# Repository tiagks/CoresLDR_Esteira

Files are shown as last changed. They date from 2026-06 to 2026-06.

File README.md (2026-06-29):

# Sensor de cores feito com um resistor LDR

## Objetivo

Desenvolver um sistema embarcado baseado no microcontrolador RP2040 capaz de identificar a cor de brinquedos em uma esteira de produção por meio de um sensor LDR, acionando um servomotor acoplado a um braço deflector para direcionar ou descartar automaticamente cada peça conforme sua cor, garantindo o controle de qualidade na linha de produção.

## Descrição Geral do Sistema

O sistema utiliza três LEDs (vermelho, verde e azul) que iluminam o objeto sobre a esteira sequencialmente. Para cada cor de LED acesa, um LDR mede a tensão refletida pelo objeto via ADC do RP2040 — formando uma assinatura RGB em voltagem para cada peça.

Antes de entrar em operação, o sistema passa por duas etapas de calibração via interface serial (UART/USB): primeiro, a calibração do tempo de decaimento do LDR (para garantir que o canal anterior apagou completamente antes de acender o próximo); depois, o treinamento de até 7 perfis de cor, incluindo obrigatoriamente o perfil NONE — a assinatura da esteira vazia, usada como filtro de ruído.

Durante a operação contínua, a cada leitura o firmware calcula a distância euclidiana no espaço RGB entre a leitura atual e todos os perfis treinados. Um filtro de limiar rejeita reflexos fracos da própria esteira. Se uma peça válida for identificada, o servomotor é travado no ângulo configurado para aquela cor por 2,8 segundos — tempo suficiente para a peça passar pelo braço deflector e ser direcionada ou descartada. Um LED RGB de status pisca em branco enquanto o sistema aguarda peças.

Toda a configuração e monitoramento é feita via comunicação serial (UART/USB), sem display físico.

## Diagrama de Blocos

```mermaid
flowchart LR
    C1[Inicializa o sistema] --> C2[Mede latência\ndos LEDs]
    C2 --> C3{Calibrar cor\nou iniciar sensor?}
    C3 -- Calibrar --> C4[Usuário\nescolhe a cor]
    C4 --> C5[Coloca objeto\nno sensor]
    C5 --> C6[LEDs piscam\nsequencialmente]
    C6 --> C7[LDR registra\nresistência por canal]
    C7 --> C8[Divisor de tensão\nconverte em tensão]
    C8 --> C9[ADC do RP2040\nlê os valores]
    C9 --> C10[RP2040 armazena\nassinatura RGB]
    C10 --> C11[Usuário define\nângulo do servo]
    C11 --> C3
    C3 -- Iniciar sensor --> OP1[LEDs piscam\nsequencialmente]
    OP1 --> OP2[LDR registra\nresistência R, G, B]
    OP2 --> OP3[Divisor de tensão\nconverte em tensão]
    OP3 --> OP4[ADC do RP2040\nlê os valores]
    OP4 --> OP5[Firmware compara com\ncalibrações armazenadas]
    OP5 -- Cor reconhecida --> OP6[Servo aciona no\nângulo calibrado]
    OP5 -- Esteira vazia\nou ruído --> OP7[Aguarda\nLED pisca branco]
    OP6 --> OP8{Cor correta?}
    OP8 -- Sim --> OP9[Braço para a direita\nPeça segue produção]
    OP8 -- Não --> OP10[Braço para a esquerda\nPeça descartada]
```

## Hardware

### Esquema Elétrico do sensor de cor LDR
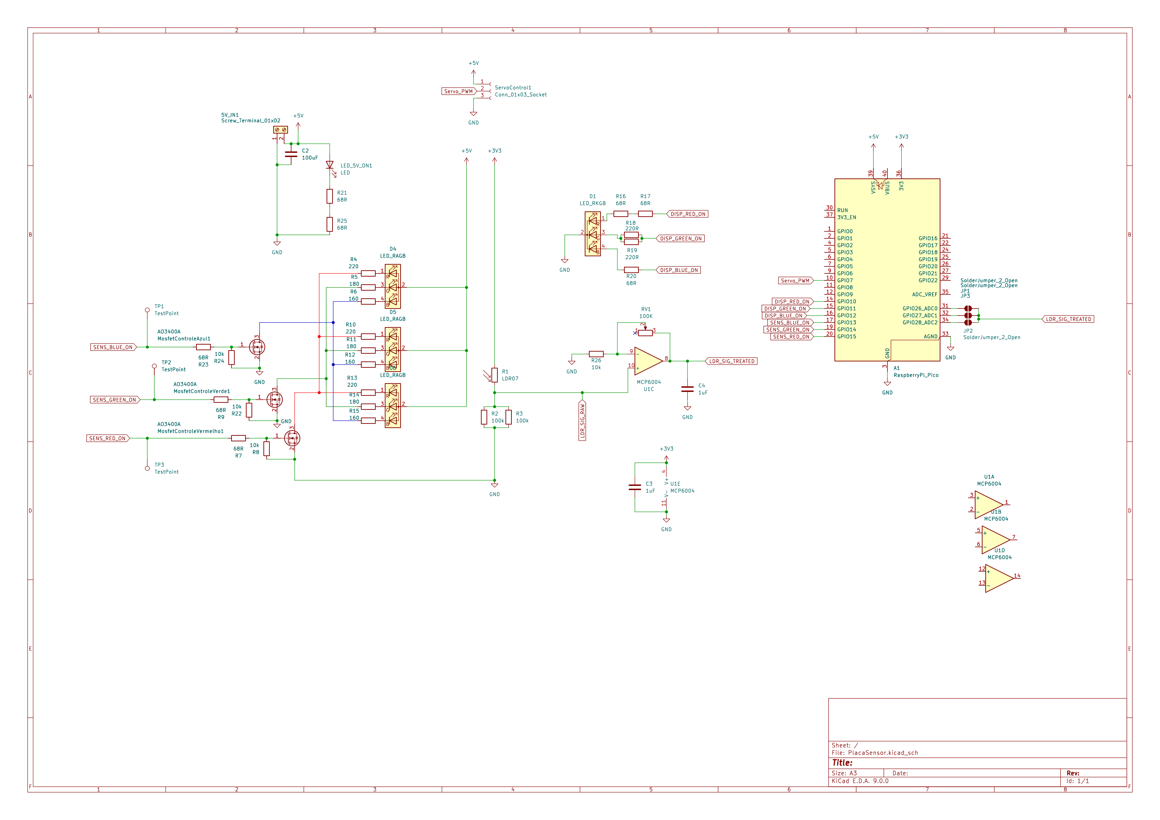
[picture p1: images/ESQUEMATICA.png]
Esquemático


### PCB do Sensor

#### Top Layer

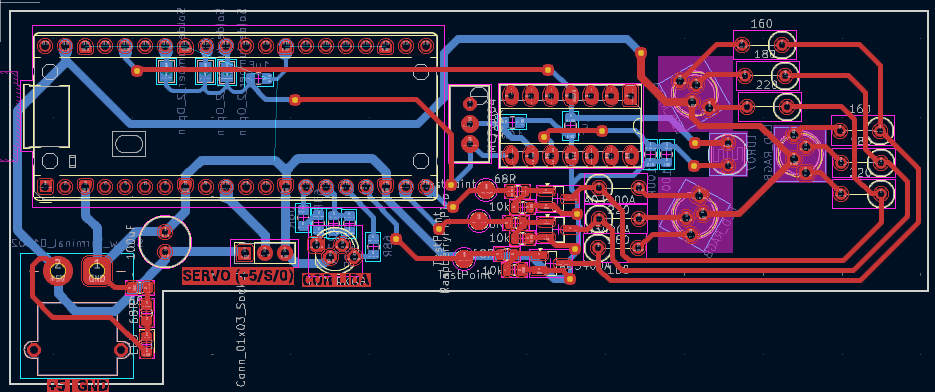
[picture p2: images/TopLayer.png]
PCB Top Layer do controlador


#### Bottom Layer

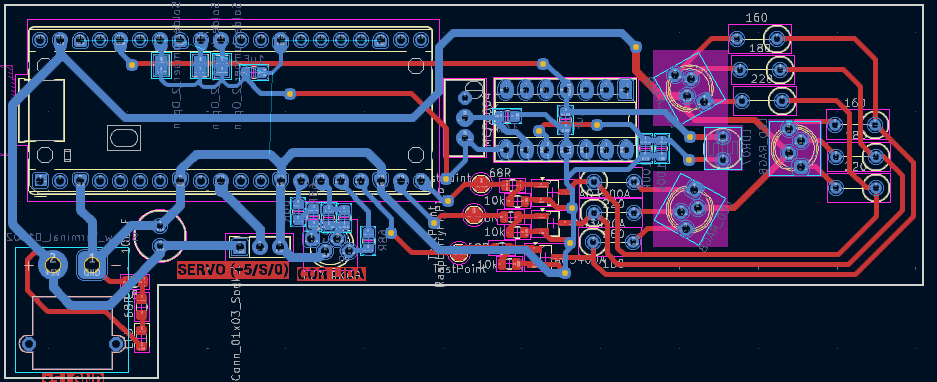
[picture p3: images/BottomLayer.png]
PCB Bottom Layer do controlador


## Funcionalidades

- Leitura analógica de cor via sensor LDR
- Condicionamento de sinal (amplificação/filtragem)
- Classificação da cor identificada via firmware no RP2040
- Acionamento automático do motor da esteira/atuador

## Projeto Finalizado
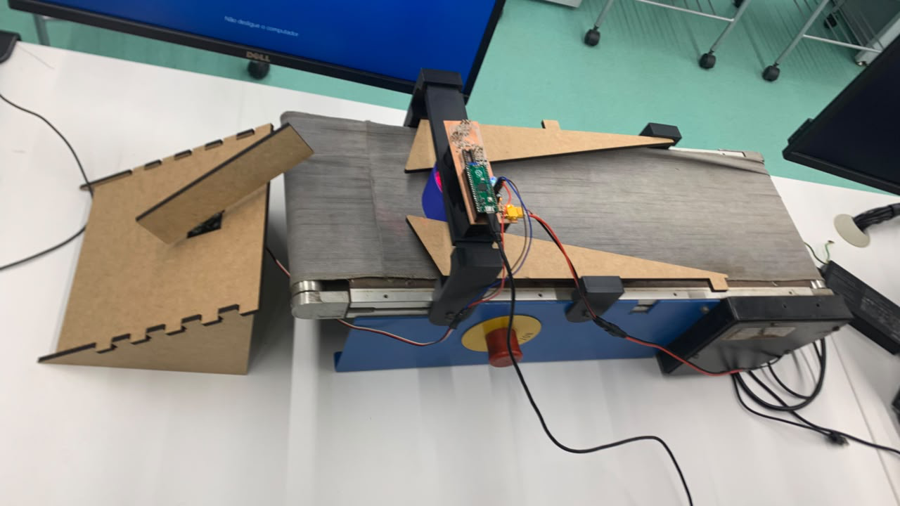
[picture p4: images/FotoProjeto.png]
Projeto Finalizado

## Estrutura do Repositório

```
CoresLDR_Esteira/
├── README.md
├── LICENSE    
├── Codigo/          # Código-fonte em C (SDK RP2040)
├── docs/                # Relatório técnico e apresentação
├── GerbersPCB/           # Arquivos relacionados a fabricação da PCB
├── images/              # Fotos do projeto e PCB
└── Solid_Parts/         # Arquivos da estrutura mecânica (SLDPRT) 

```

## Documentação

- 📄 **Artigo técnico:** [docs/ArtigoSensorCores.pdf](docs/ArtigoSensorCores.pdf)
- 🎤 **Apresentação:** [docs/apresentacao.pptx](docs/apresentacao.pptx)

## Integrantes

| Nome | RA |
|---|-----|
| Tiago Tosto Pereira Regente | 23.00815-6 |
| Felipe Cerquiaro da Silva Trancho | 22.01106-4 |
| Pedro Frehse Baltar | 23.95013-7 |
| Rafael Panicali Mello Guida | 21.00423-4 |

## Disciplina

Projeto Integrado das Disciplinas Instrumentação e Microcontroladores e Sistemas Microcontrolados — Instituto Mauá de Tecnologia
Prof. Andressa Martins e Prof. Rodrigo França

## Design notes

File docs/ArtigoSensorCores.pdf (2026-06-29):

PROJETO DE PROTÓTIPO DE SENSOR DE DETECÇÃO DE COR

Felipe Cerquiaro da Silva Trancho 1

; Pedro Frehse Baltar 1

; Rafael Panicali Mello Guida 1 ;
Tiago Tosto Pereira Regente 1

; Andressa Martins 2

; Rodrigo França 2

1 Aluno(a) do Instituto Mauá de Tecnologia (IMT); 2 Professor(a) do Instituto Mauá de Tecnologia (IMT).

Resumo. Este projeto apresenta o desenvolvimento e um sistema automático de separação de objetos baseado na detecção de cor. O sistema é composto por um sensor analógico, com 3 LEDs RGB (vermelho, verde e azul), um fotoresistor (LDR) que capta a luz refletida, um microcontrolador RP2040 para o processamento de sinais e um servomotor para separar os objetos, tudo acoplado a uma esteira. O funcionamento consiste na emissão sequencial de cores pelos LEDs, captura da reflexão pelo LDR, análise das tensões correspondentes e comparação com valores de calibração prévia pelo microcontrolador e acionamento do servomotor para realizar a separação automática dos objetos da esteira. Esse trabalho integra conceitos de instrumentação eletrônica e microcontroladores, demonstrando uma aplicação prática de automação em processos de separação reais. Os resultados obtidos comprovam a solução proposta, evidenciando a eficácia da utilização de sensores de detecção de cor como método de separação.

Introdução

A automação de processos de separação e classificação de objetos é essencial em diversos setores industriais, onde a necessidade de velocidade e precisão é importante. Tradicionalmente, os processos de separação, quando feitas com a ação humana, apresentam limitações significativas na eficiência, alto custo operacional e possíveis erros humanos. A automatização desses processos eleva a produtividade e garante uma padronização e qualidade do produto.
A detecção de cor é um dos métodos mais eficazes e econômicos para classificação e separação de produtos. Aplicações práticas incluem separação de peças de brinquedos, de artigos manufaturados e de frutas em diferentes estágios por exemplo. Esses sistemas demandam sensores capazes de capturar e diferenciar informações cromáticas com precisão e microcontroladores capazes de processar sinais em tempo real.
Este projeto propõe o desenvolvimento de um sistema automático de separação por detecção de cor, integrando um sensor analógico, com LED RGB e fotoresistor (LDR), um microcontrolador RP2040 e um servomotor à uma esteira. O sistema realiza a separação através de uma comparação das tensões captadas pelo LDR com valores de uma calibração prévia, assim acionando o servomotor segregando os objetos colocados na esteira.
O objetivo deste trabalho é demonstrar na prática a viabilidade técnica de um sistema automático de detecção de cor, contribuindo para a compreensão das disciplinas de Instrumentação e Microcontroladores.

Material e Métodos

Fundamentos teóricos

A detecção da cor do objeto é baseada pelo princípio de reflexão de luz. Segundo professor Asth ([2023]), “A reflexão da luz é um fenômeno óptico onde a luz incide em uma superfície refletora e retorna à sua fonte original ou ao meio”. Ou seja, quando uma fonte luminosa incide sobre uma superfície, parte dessa luz é absorvida pelo material e a outra é refletida. A intensidade e o comprimento de onda da parte refletida dependem das propriedades ópticas da superfície, como sua coloração e textura.

O LDR (Light Dependent Resistor), ou fotoresistor, é um componente semicondutor passivo cuja resistência elétrica diminui à medida que a intensidade da luz incidente aumenta. Eles são tipicamente fabricados com materiais semicondutores de alta resistência, como o Sulfeto de Cádmio (CdS). O princípio de funcionamento baseia-se no efeito fotoelétrico interno:
- No escuro, o material semicondutor possui poucos elétrons livres em sua banda de condução. A maioria está presa na banda de valência, resultando em uma resistência altíssima (frequentemente na casa dos Megaohms).
- Quando fótons de luz atingem a superfície do LDR com energia superior ao bandgap (a lacuna de energia do semicondutor), eles transferem essa energia para os elétrons.
- Esses elétrons saltam da banda de valência para a banda de condução, tornando-se portadores de carga livres.
- Quanto mais luz (mais fótons), mais portadores de carga são liberados e, consequentemente, menor se torna a resistência elétrica do material.
Neste protótipo utilizamos LED RGB como fonte luminosa do sensor, emitindo luz das cores vermelha, verde e azul sequencialmente. Quando ligados, as características da luz refletida pelo objeto dependeram da cor da sua superfície. Com isso, o objeto da cor vermelha refletia, principalmente, vermelha, e assim sucessivamente para as demais cores.
Utilizamos também o LDR como principal componente do sensor, aquele que detectou a cor do objeto. O LDR ao receber a luz refletida pelo objeto, varia sua resistência proporcionalmente à intensidade de luz captada.
Assim, o fluxo da emissão e captação de luz ficou da seguinte maneira: o LED RGB emitiu a luz na cor vermelha; a luz refletiu no objeto foi percebida pelo LDR; o LED mudou para a cor verde; LDR percebeu a reflexão nessa cor; o LED mudou para azul; o LDR percebe a reflexão. Essas mudanças de coloração foram praticamente contínuas, para que a detecção fosse mais rápida possível.

Equipamentos

Utilizamos uma esteira elétrica que estava inutilizada para simular uma aplicação real. Para as estruturas acopladas a essa esteira, usamos a impressão 3D para confeccioná-las. Foram fabricados, em PLA e PETG, dois suportes baixos Figura 1, dois suportes altos Figura 2, um encapsulamento do sensor Figura 3, uma base para fixar o encapsulamento Figura 4 e três peças de teste Figura 5.

Figura 1 – Suporte baixo

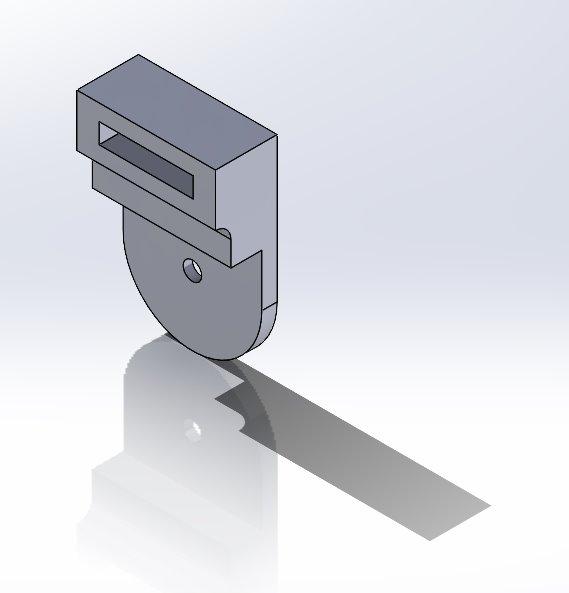
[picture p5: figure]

Fonte: Autores, 2026.

Figura 2 – Suporte alto

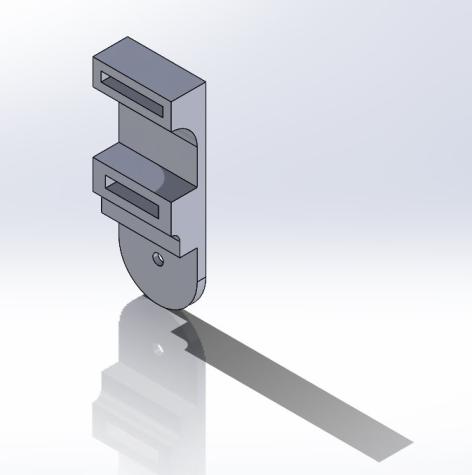
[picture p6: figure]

Fonte: Autores, 2026.

Figura 3 – Encapsulamento do sensor

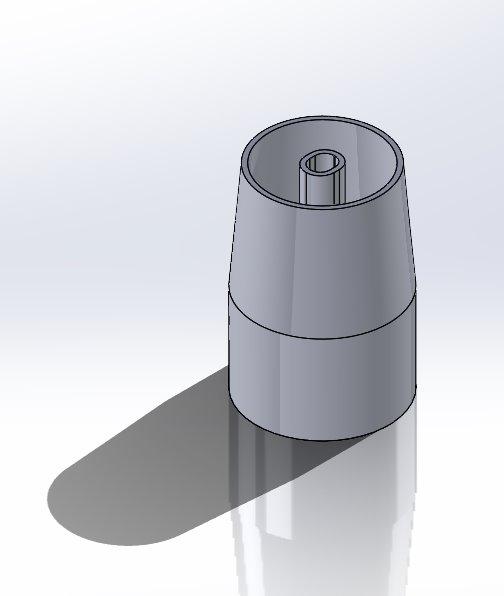
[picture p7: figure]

Fonte: Autores, 2026.

Figura 4 – Base do sensor

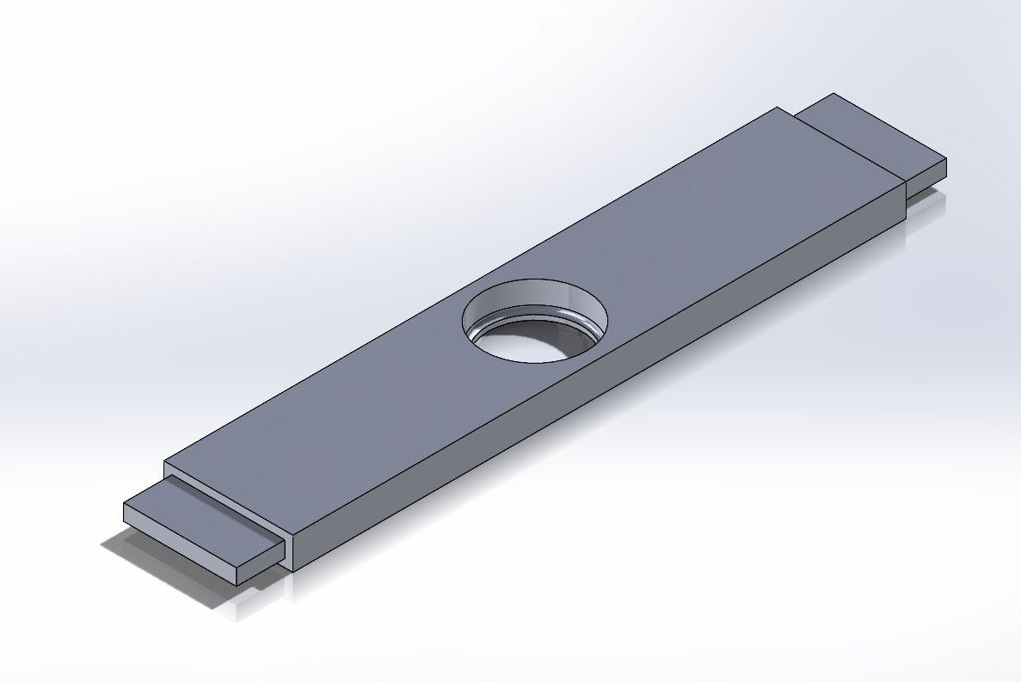
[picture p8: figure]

Fonte: Autores, 2026.

Figura 5 – Peça de teste

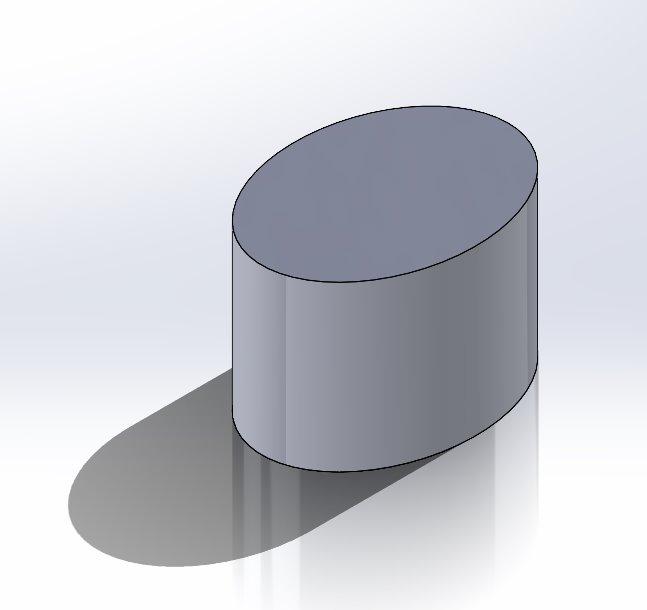
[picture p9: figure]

Fonte: Autores, 2026.

Também cortamos a laser placas de MDF de 6mm para fabricar um funil, duas chapas da Figura 6 e uma rampa, sendo duas laterais da rampa Figura 7 e a rampa Figura 8.

Figura 6 – Funil

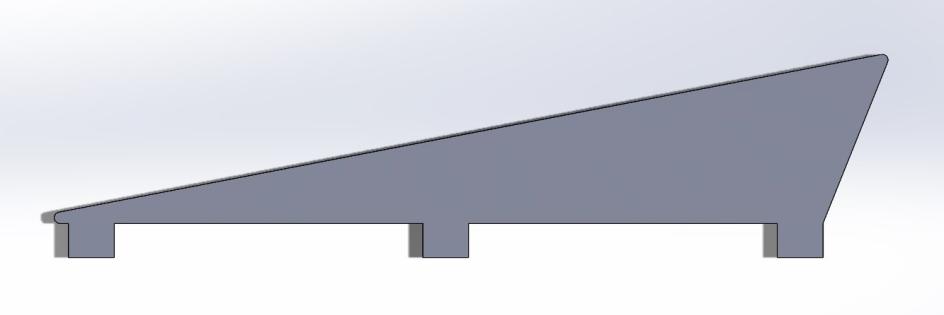
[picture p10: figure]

Fonte: Autores, 2026.

Figura 7 – Lateral da rampa

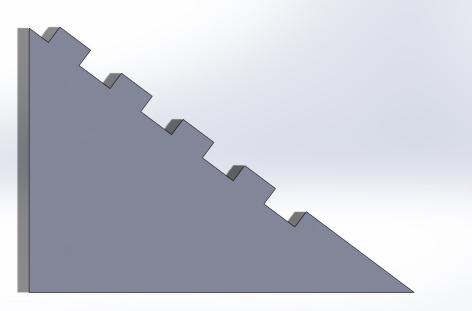
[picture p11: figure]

Fonte: Autores, 2026.

Figura 8 – Rampa

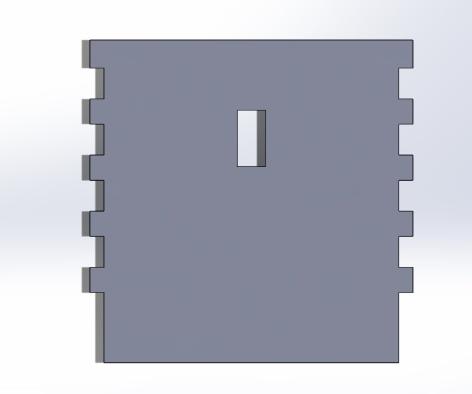
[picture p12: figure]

Fonte: Autores, 2026.

Utilizamos o microcontrolador RP2040 para o a leitura e tratamento de sinal do sensor, emissão sequencial dos LEDs, processamento de dados de cor e acionamento do servomotor.
Para integrar todos os componentes eletrônicos e o microcontrolador, fabricamos uma placa de circuito impressa (PCB) Figura 9.

Figura 9 – Esquema da PCB

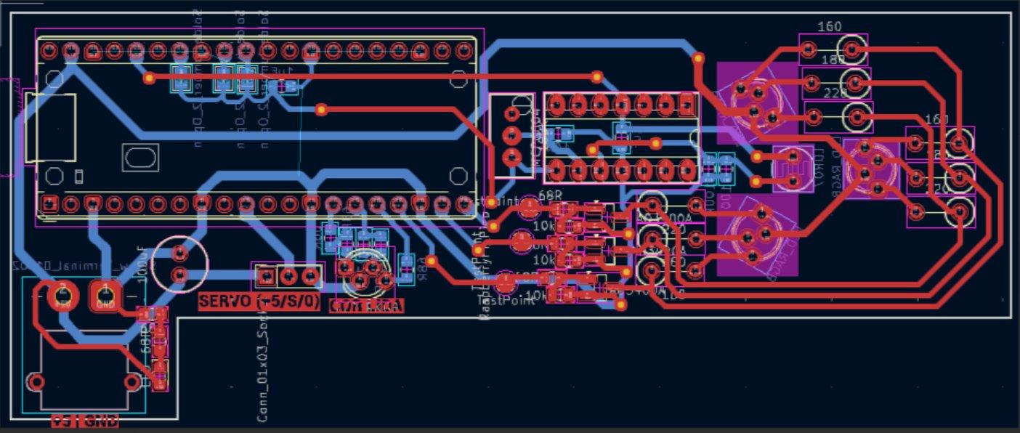
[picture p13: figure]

Fonte: Autores, 2026.

Procedimentos

O firmware do sistema foi escrito em linguagem C, utilizando o SDK oficial do Raspberry Pi Pico (pico-sdk), e organiza-se em quatro blocos funcionais principais: (i) configuração de hardware e constantes do sistema; (ii) tratamento de sinais, isto é, a captura da tensão refletida pelo LDR para cada cor do LED; (iii) calibragem, dividida em calibração da latência de decaimento do LDR e treinamento dos perfis de cor; e (iv) o algoritmo de detecção de cor propriamente dito, que compara a leitura atual com os perfis treinados e aciona o servomotor. O fluxo do programa segue um laço principal não bloqueante que lê comandos do terminal serial e despacha para a rotina correspondente. Cada bloco é detalhado a seguir, com os trechos de código correspondentes.
a) Configuração de hardware e constantes
No início do programa são definidos os pinos GPIO utilizados pelo servomotor, pelos LEDs RGB de status, pelos LEDs do sensor e pelo canal ADC do LDR, além das constantes de calibração do PWM e dos limiares de decisão do algoritmo de classificação:
#define SERVO_PIN | 7

#define DISP_RED_PIN | 10

#define DISP_GREEN_PIN 11

#define DISP_BLUE_PIN | 12

#define SENS_BLUE_PIN | 13

#define SENS_GREEN_PIN 14

#define SENS_RED_PIN | 15

#define LDR_ADC_PIN | 28 // GPIO 28 mapeia para ADC2

#define LDR_ADC_CH | 2

#define MATCH_THRESHOLD | 0.25f

#define BELT_DIRT_THRESHOLD | 0.18f // filtro de ruido da esteira

O parâmetro MATCH_THRESHOLD define a distância máxima, em Volts, entre a leitura atual e um perfil de cor cadastrado para que esse perfil seja considerado uma correspondência válida. Já o BELT_DIRT_THRESHOLD atua como um filtro de ruído (“noise gate”): ele exige que a leitura atual se diferencie da leitura da esteira vazia (perfil “NONE”) por uma margem mínima, evitando que pequenas sujeiras, ranhuras ou variações naturais de reflexão da esteira sejam interpretadas como objetos.

b) Tratamento de sinais – captura da cor
A leitura de cada canal de cor é feita acionando individualmente o LED correspondente (vermelho, verde ou azul), aguardando um curto intervalo para estabilização da reflexão e, em seguida, amostrando a tensão do LDR diversas vezes para reduzir o ruído de leitura por meio de uma média aritmética:
float sample_raw_voltage_averages(int iterations) {
uint32_t total = 0;
for (int i = 0; i < iterations; i++) {
total += adc_read();
sleep_us(30);
}
return ((float)total / (float)iterations) * ADC_CONV;
}

void capture_raw_rgb(float *r_out, float *g_out, float *b_out) { turn_off_sensor_rgb();
sleep_ms(30);

gpio_put(SENS_RED_PIN, 1); sleep_ms(65);
*r_out = sample_raw_voltage_averages(20); gpio_put(SENS_RED_PIN, 0); sleep_ms(decay_cooldown_r);

gpio_put(SENS_GREEN_PIN, 1); sleep_ms(65);
*g_out = sample_raw_voltage_averages(20); gpio_put(SENS_GREEN_PIN, 0); sleep_ms(decay_cooldown_g);

gpio_put(SENS_BLUE_PIN, 1); sleep_ms(65);
*b_out = sample_raw_voltage_averages(20);
gpio_put(SENS_BLUE_PIN, 0); sleep_ms(decay_cooldown_b);
}
Os intervalos decay_cooldown_r, decay_cooldown_g e decay_cooldown_b correspondem ao tempo necessário para que o LDR retorne ao seu estado de repouso após cada pulso de luz, evitando que a leitura de um canal seja contaminada pela luz residual do canal anterior.
c) Calibragem – latência do LDR e perfis de cor
Como o tempo de decaimento do LDR varia com a luminosidade ambiente e com o próprio componente, foi implementada uma rotina de auto-calibração que mede, para cada cor, o tempo necessário para a tensão cair até um limiar próximo do valor ambiente:
for (int c = 0; c < 3; c++) {
gpio_put(target_pin, 1);
sleep_ms(250);
float v_lit = sample_raw_voltage_averages(35);
float peak_delta = (v_lit > v_ambient) ? (v_lit - v_ambient) : 0.05f; float target_decay_threshold = v_ambient + (peak_delta * 0.20f);

gpio_put(target_pin, 0);
uint32_t decay_start = to_ms_since_boot(get_absolute_time()); uint32_t elapsed_ms = 0;

while (elapsed_ms < 2000) {
float current_v = sample_raw_voltage_averages(5);
if (current_v <= target_decay_threshold) break;
sleep_ms(1);
elapsed_ms = to_ms_since_boot(get_absolute_time()) - decay_start; }
calibrated_latencies[c] = (elapsed_ms > 20) ? elapsed_ms : 20;
}
Os | valores | resultantes | (calibrated_latencies) | são | então | usados | para | atualizar
decay_cooldown_r, decay_cooldown_g e decay_cooldown_b, tornando o tempo de assentamento do sensor adaptativo às condições reais de operação.
Já o treinamento de perfis de cor associa, para cada classe pré-definida (vermelho, verde, azul, amarelo, laranja, rosa e o perfil “NONE” da esteira vazia), a assinatura de tensão RGB lida pelo sensor e o ângulo de servomotor correspondente àquela classe:
capture_raw_rgb(&r, &g, &b);

strcpy(trained_profiles[chosen_idx].name, color_table[chosen_idx].label); trained_profiles[chosen_idx].r_val = r; trained_profiles[chosen_idx].g_val = g; trained_profiles[chosen_idx].b_val = b; trained_profiles[chosen_idx].servo_angle = (uint16_t)parsed_angle;

trained_profiles[chosen_idx].disp_r = color_table[chosen_idx].r_disp; trained_profiles[chosen_idx].disp_g = color_table[chosen_idx].g_disp; trained_profiles[chosen_idx].disp_b = color_table[chosen_idx].b_disp;

if (!trained_profiles[chosen_idx].active) { trained_profiles[chosen_idx].active = true; active_profile_count++;
}
d) Algoritmo de detecção de cor e fluxo do programa
A cada ciclo de leitura, o algoritmo calcula a distância euclidiana entre o vetor de tensão atual (R, G, B) e cada perfil treinado, selecionando o perfil mais próximo:
for (int i = 0; i < TARGET_COUNT; i++) {
if (!trained_profiles[i].active) continue;

float delta_r = cur_r - trained_profiles[i].r_val; float delta_g = cur_g - trained_profiles[i].g_val; float delta_b = cur_b - trained_profiles[i].b_val; float calculated_distance = sqrtf((delta_r * delta_r) + (delta_g * delta_g) +
(delta_b * delta_b));

if (calculated_distance < minimum_calculated_distance) { minimum_calculated_distance = calculated_distance; closest_slot_match = i;
}
}
Em paralelo, calcula-se também a distância entre a leitura atual e o perfil “NONE” (esteira vazia), usada como filtro de ruído:
float dist_from_none = 999.0f;
if (trained_profiles[6].active) {
float d_r = cur_r - trained_profiles[6].r_val;
float d_g = cur_g - trained_profiles[6].g_val;
float d_b = cur_b - trained_profiles[6].b_val;
dist_from_none = sqrtf((d_r * d_r) + (d_g * d_g) + (d_b * d_b));
}
Por fim, a decisão de acionamento do servomotor combina os dois critérios: se a menor distância encontrada estiver dentro do MATCH_THRESHOLD e a leitura corresponder ao perfil da esteira vazia ou estiver muito próxima dele (abaixo do BELT_DIRT_THRESHOLD), o sistema mantém o servomotor na posição neutra; caso contrário, considera-se que um objeto válido foi detectado e o servomotor é travado na posição de separação correspondente por 2,8 segundos, tempo suficiente para o objeto ser desviado da esteira:
if (closest_slot_match != -1 && minimum_calculated_distance <= MATCH_THRESHOLD) {

if (closest_slot_match == 6 || dist_from_none < BELT_DIRT_THRESHOLD) {
// Esteira vazia ou ruido: mantem servo na posicao neutra
if (!is_servo_locked) {
current_active_angle = trained_profiles[6].active ? trained_profiles[6].servo_angle : 90; write_servo_angle(current_active_angle);
}
} else {
// Objeto valido detectado: trava o servo na posicao de separacao servo_unlock_time = make_timeout_time_ms(2800);
is_servo_locked = true;
current_active_angle = trained_profiles[closest_slot_match].servo_angle; write_servo_angle(current_active_angle); set_display_rgb(trained_profiles[closest_slot_match].disp_r, trained_profiles[closest_slot_match].disp_g, trained_profiles[closest_slot_match].disp_b); }
}
Esse laço de classificação é executado repetidamente dentro do modo de triagem contínua, que também verifica, a cada iteração, se o tempo de bloqueio do servomotor já expirou, liberando-o para a próxima leitura assim que o objeto anterior é removido da esteira.

Descrição

De forma resumida, o sistema funciona como uma esteira de triagem autônoma: o microcontrolador RP2040 comanda sequencialmente os três LEDs do sensor (vermelho, verde e azul), lê em cada janela de tempo a tensão refletida pelo LDR e monta um vetor de três tensões que funciona como uma “assinatura” da cor do objeto posicionado sobre o sensor. Essa assinatura é comparada, por distância euclidiana, com os perfis de cor previamente cadastrados pelo usuário – processo chamado de calibragem ou treinamento, realizado uma única vez antes da operação contínua.
Antes de iniciar a triagem, é necessário executar a calibração da latência do LDR (opção [c] do menu), que ajusta automaticamente o tempo de assentamento do sensor às condições de luz ambiente, e treinar ao menos o perfil “NONE” com a esteira vazia, além dos perfis das cores que se deseja separar (opção [t]). Com os perfis cadastrados, o sistema pode operar em modo de verificação manual (opção [m], útil para depuração) ou em modo de triagem contínua (opção [a]), no qual a esteira física pode ser ligada e os objetos passam continuamente pelo sensor.
Quando um objeto colorido válido é identificado, o microcontrolador aciona o servomotor para o ângulo previamente associado àquela cor, desviando o objeto para a saída correspondente da rampa, e mantém essa posição travada por 2,8 segundos para garantir que o objeto seja efetivamente separado antes que o servomotor retorne à posição neutra e o sistema volte a analisar a esteira. Enquanto nenhum objeto é detectado, um indicador luminoso branco pulsa de forma intermitente nos LEDs de status, sinalizando visualmente que o sistema está ativo e aguardando a passagem de um novo item.

Resultados e Discussão

Para validar o funcionamento do sensor, foram realizadas leituras de tensão nos três canais (R, G e B) para quatro situações: a esteira vazia (perfil “Nenhum”, usado como linha de base) e três objetos de teste coloridos (azul, verde e vermelho). A Tabela 1 apresenta os valores médios de tensão, em Volts, obtidos para cada canal do sensor em cada situação.
Tabela 1 – Tensão média (V) lida pelo sensor RGB para cada objeto de teste
Objeto | Sensor R (V) | Sensor G (V) | Sensor B (V)
Nenhum (Esteira) | 2,408 | 1,834 | 1,729
Objeto Azul | 2,820 | 2,418 | 2,606
Objeto Verde | 2,768 | 2,268 | 1,994
Objeto Vermelho | 2,411 | 1,838 | 1,735

A Figura 1 apresenta o mesmo conjunto de dados em forma de gráfico de barras, facilitando a comparação entre os três canais para cada objeto. Observa-se que, para a esteira vazia (perfil “Nenhum”), as três tensões ficam próximas e relativamente baixas nos canais G e B, servindo como linha de base do sistema. Já para os objetos coloridos, o canal correspondente à cor do objeto tende a apresentar a maior tensão relativa: o objeto azul resulta na maior leitura do canal B (2,606 V) entre os três objetos, enquanto o objeto vermelho mantém uma assinatura próxima à do perfil “Nenhum”, já que a superfície da esteira também reflete predominantemente no vermelho. O objeto verde, por sua vez, apresenta a maior tensão absoluta no canal R, o que se explica pelo fato de o LDR utilizado ser mais sensível à faixa de comprimento de onda emitida pelo LED vermelho do que pela emissão verde propriamente dita, evidenciando uma limitação conhecida desse tipo de sensor analógico simples.
Figura 1 – Comparação de tensão RGB lida pelo sensor para cada objeto de teste

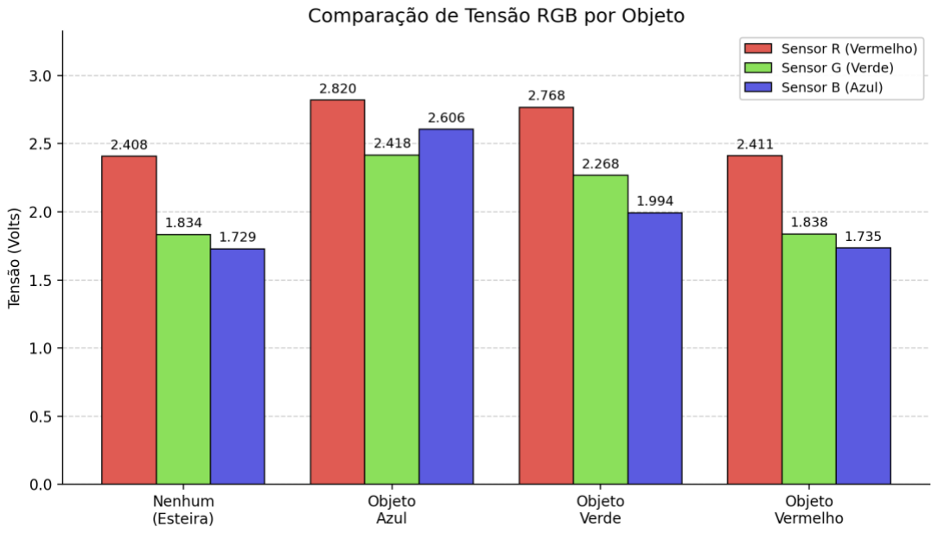
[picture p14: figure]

Fonte: Autores, 2026.

O circuito ilustrado na Figura 2 é um Divisor de Tensão. O sinal (LDR_SIG_RAW) é a queda de tensão sobre o conjunto de resistores na parte inferior (R2 e R3). É importante ressaltar que, neste caso, foram utilizados 2 resistores para atingir o valor de 50k pois eles vieram de um kit de componentes SMD onde o valor de 50k não estava disponível.
Figura 2 – Diagrama elétrico divisor de tensão LDR

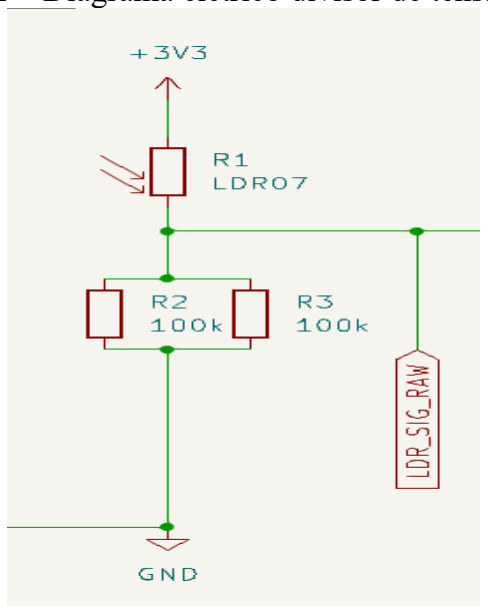
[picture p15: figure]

Fonte: Autores, 2026

Simplificação do Circuito
Vamos simplificar a resistência inferior (Req), que é o paralelo entre R2 e R3:

Req =

100k ⋅ 100k
100k + 100k

= 50kΩ

Equação do Divisor de Tensão
A tensão de saída (Vout) medida no nó central em relação ao GND é governada pela lei de Ohm aplicada ao divisor de tensão:
Vout = Vin ⋅ (
Req

RLDR + Req)

Substituindo os valores conhecidos do seu esquemático:

Vout = 3.3 ⋅ (

RLDR + 50000)

- No escuro: RLDR é muito grande (ex: 1MΩ). O denominador fica enorme e Vout se aproxima de 0V.
- Na luz: RLDR diminui drasticamente (ex: 1MΩ) O denominador diminui, aproximando-se do valor do numerador, e Vout se aproxima de 3,3V
Modelagem da Resistência em Função da Luz
Para modelar o sistema completo, precisamos relacionar RLDR com a iluminância (E, medida em Lux). A relação de um LDR típico não é linear, mas sim logarítmica/exponencial, dada pela equação empírica:
RLDR = C ⋅ E

−γ
Onde:
- C é a resistência do LDR no escuro ou a uma iluminância de referência (ex: 1 Lux).
- γ (Gama) é o coeficiente de sensibilidade do LDR, que determina a inclinação da curva logarítmica (tipicamente entre 0.6 e 0.9).

Equação Final do Sistema
Substituindo o modelo do LDR na equação do divisor de tensão, obtemos a função de transferência completa do seu circuito, que relaciona diretamente os Lux incidentes com a Tensão lida pelo ADC:
Vout(E) = 3.3 ⋅ (

50000
C ⋅ E⁻γ + 50000)

Conclusões

O protótipo desenvolvido demonstrou que é tecnicamente viável separar objetos por cor utilizando apenas um sensor RGB de baixo custo, um LDR e um microcontrolador RP2040, sem a necessidade de módulos sensores dedicados de cor. A estratégia de emissão sequencial de luz vermelha, verde e azul, associada à leitura do LDR em cada janela de tempo, mostrou-se suficiente para gerar uma assinatura de tensão distinta para cada classe de objeto, conforme evidenciado pelos valores apresentados na Tabela 1.
O algoritmo de classificação por distância euclidiana entre o vetor de tensão lido e os perfis previamente calibrados se mostrou eficaz para diferenciar os objetos coloridos do fundo da esteira, especialmente após a introdução do filtro de ruído (noise gate) baseado na comparação com o perfil “NENHUM”. Esse cuidado foi essencial para evitar acionamentos indevidos do servomotor causados por sujeira ou variações naturais de reflexão da esteira.
A calibração automática do tempo de decaimento do LDR (rotina de auto-tuning) também se mostrou um diferencial importante, pois compensou a variação do tempo de resposta do componente em diferentes condições de luminosidade ambiente, tornando o sistema mais robusto e fácil de recalibrar caso o sensor seja reposicionado.
Como trabalhos futuros, sugere-se a ampliação do número de classes de cores treinadas, a substituição do LDR por um sensor de cor digital (como o TCS3200) para reduzir a sensibilidade à luz ambiente, e a integração de um encoder na esteira para sincronizar a leitura com a velocidade de deslocamento dos objetos.

Referências Bibliográficas

AMHANI, Ahmad; IQBAL, Zaki. Automated Color Sensor System Using LDR and RGB Leds Controlled by Arduino. ARPN Journal of Engineering and Applied Sciences, v. 12, n. 19, p. 5532– 5537, out. 2017. Disponível em: https://aurak.ac.ae/publications/Automated-Color-Sensor-System-Using-LDR-and-RGB-Leds-Controlled-by-Arduino.pdf. Acesso em: 28 jun. 2026. ASTH, Rafael. Reflexão da Luz: suas leis, ângulos de incidência e reflexão. Toda Matéria, [s.d.]. Disponível em: https://www.todamateria.com.br/reflexao-da-luz/. Acesso em: 28 jun. 2026. GTA/UFRJ. LDR – Light Dependent Resistor. Grupo de Teleinformática e Automação, Universidade
Federal | do | Rio | de | Janeiro, | [s.d.]. | Disponível | em:
https://www.gta.ufrj.br/grad/01_1/contador555/ldr.htm. Acesso em: 28 jun. 2026.
RASPBERRY PI FOUNDATION. RP2040 Datasheet. Cambridge: Raspberry Pi Foundation, 2024. Disponível em: https://datasheets.raspberrypi.com/rp2040/rp2040-datasheet.pdf. Acesso em: 28 jun. 2026.
UNIVERSIDADE FEDERAL DE OURO PRETO. Sensor de Luminosidade – LDR. Roteiro de
prática, | Departamento | de | Física, | [s.d.]. | Disponível | em:
https://professor.ufop.br/sites/default/files/adrielle/files/roteiro_da_pratica_de_ldrs2-adrielle_0.pdf. Acesso em: 28 jun. 2026.

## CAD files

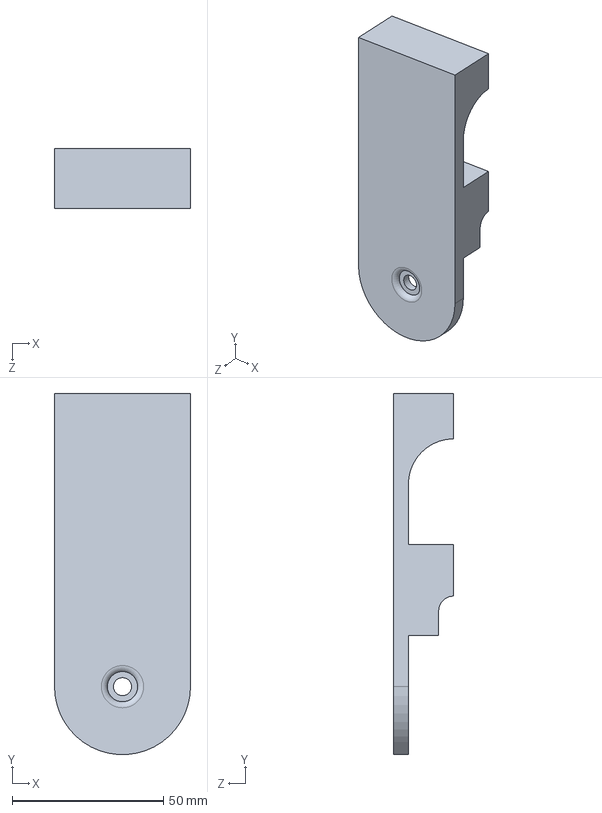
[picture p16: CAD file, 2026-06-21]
Solid_Parts/Suporte sensor cima.SLDPRT
45.0 x 119.4 x 20.0 mm

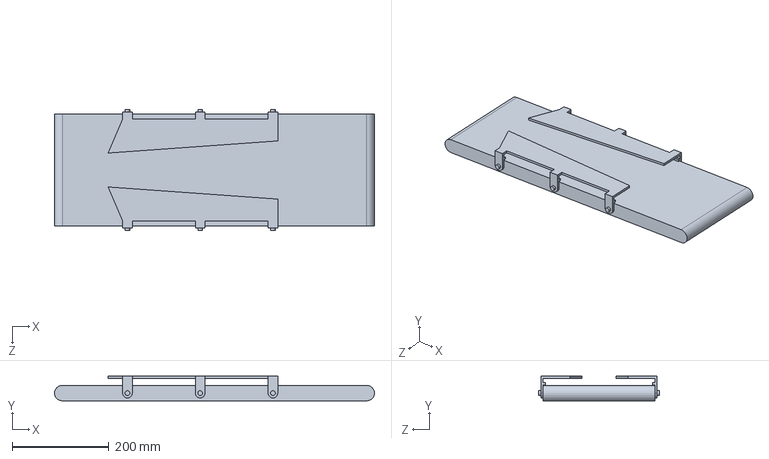
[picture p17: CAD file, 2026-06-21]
Solid_Parts/Esteira.SLDPRT
660.0 x 51.0 x 250.0 mm

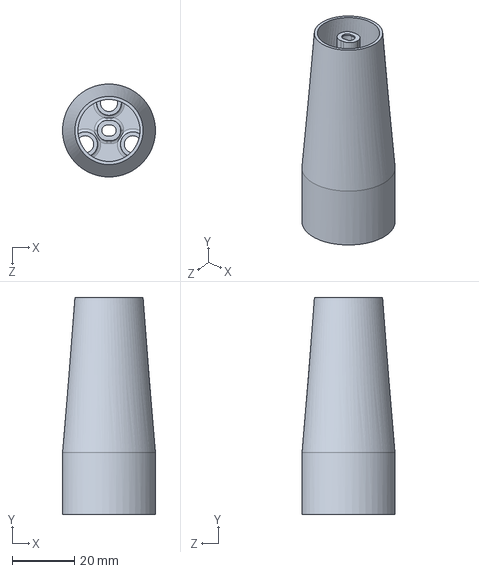
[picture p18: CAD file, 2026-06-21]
Solid_Parts/Sensor com LDR e LED.SLDPRT
30.0 x 70.0 x 30.0 mm

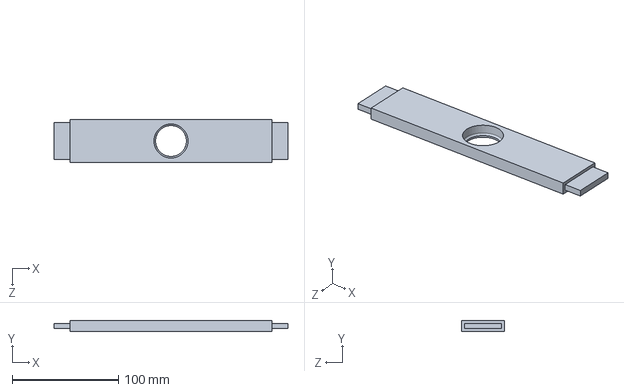
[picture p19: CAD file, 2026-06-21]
Solid_Parts/Barra superior.SLDPRT
220.0 x 10.0 x 40.0 mm

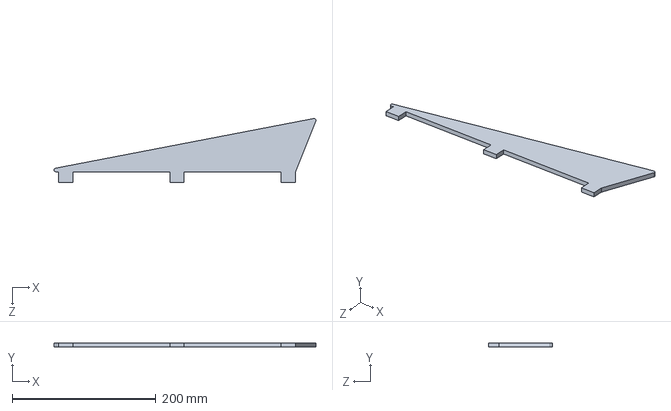
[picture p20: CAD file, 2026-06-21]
Solid_Parts/Chapa.SLDPRT
364.7 x 6.00 x 89.2 mm

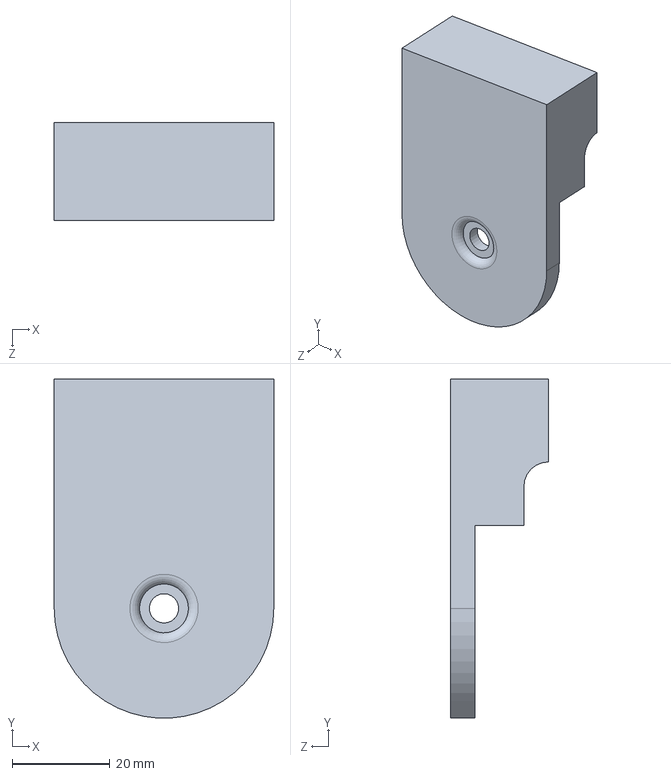
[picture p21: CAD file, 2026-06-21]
Solid_Parts/Suporte.SLDPRT
45.0 x 69.5 x 20.0 mm

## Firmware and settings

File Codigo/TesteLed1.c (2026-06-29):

#include <stdint.h>
#include <stdio.h>
#include <string.h>
#include <math.h>
#include "pico/stdlib.h"
#include "hardware/pwm.h"
#include "hardware/adc.h"

// --- HARDWARE PIN ASSIGNMENTS ---
#define SERVO_PIN        7
#define SERVO_WRAP       39062  

#define DISP_RED_PIN    10
#define DISP_GREEN_PIN  11
#define DISP_BLUE_PIN   12

#define SENS_BLUE_PIN   13
#define SENS_GREEN_PIN  14
#define SENS_RED_PIN    15

#define LDR_ADC_PIN     28  // GPIO 28 maps to ADC2
#define LDR_ADC_CH      2   // ADC Channel 2

#define PWM_MAX         65535
#define ADC_CONV        (3.3f / 4095.0f)

// --- CONFIGURABLE SELECTION THRESHOLDS ---
#define MATCH_THRESHOLD       0.25f  
#define BELT_DIRT_THRESHOLD   0.18f  // Noise gate: items must differ from NONE by at least this voltage to count

// --- PRE-MADE COLOR TARGET TABLE ---
typedef struct {
    const char* label;
    uint8_t r_disp;
    uint8_t g_disp;
    uint8_t b_disp;
} PreMadeTarget;

#define TARGET_COUNT 7
const PreMadeTarget color_table[TARGET_COUNT] = {
    {"RED",    100, 0,   0  },
    {"GREEN",  0,   100, 0  },
    {"BLUE",   0,   0,   100},
    {"YELLOW", 60,  100, 0  },
    {"ORANGE", 100, 30,  0  },
    {"PINK",   100, 0,   60 },
    {"NONE",   0,   0,   0  }  // Index 6: Background belt profile
};

typedef struct {
    char name[20];
    float r_val;
    float g_val;
    float b_val;
    uint16_t servo_angle;
    uint8_t disp_r;
    uint8_t disp_g;
    uint8_t disp_b;
    bool active;
} ColorProfile;

ColorProfile trained_profiles[TARGET_COUNT];
int active_profile_count = 0;

uint32_t decay_cooldown_r = 100; 
uint32_t decay_cooldown_g = 100;
uint32_t decay_cooldown_b = 100;
bool latency_calibrated = false; 

// Asynchronous Timing Control Registers
absolute_time_t servo_unlock_time;
bool is_servo_locked = false;
uint16_t current_active_angle = 90;

// Idle Blink Timer State Tracking
absolute_time_t next_idle_blink_time;
bool idle_blink_state = false;

void clear_serial_buffer() {
    while (getchar_timeout_us(0) != PICO_ERROR_TIMEOUT) {}
}

void turn_off_sensor_rgb() {
    gpio_put(SENS_RED_PIN, 0);
    gpio_put(SENS_GREEN_PIN, 0);
    gpio_put(SENS_BLUE_PIN, 0);
}

void set_display_rgb(uint8_t r, uint8_t g, uint8_t b) {
    pwm_set_gpio_level(DISP_RED_PIN,   (r * r * PWM_MAX) / (100 * 100));
    pwm_set_gpio_level(DISP_GREEN_PIN, (g * g * PWM_MAX) / (100 * 100));
    pwm_set_gpio_level(DISP_BLUE_PIN,  (b * b * PWM_MAX) / (100 * 100));
}

void write_servo_angle(uint16_t angle) {
    if (angle > 180) angle = 180;
    uint32_t level = 1172 + ((angle * (4687 - 1172)) / 180);
    pwm_set_gpio_level(SERVO_PIN, level);
}

float sample_raw_voltage_averages(int iterations) {
    uint32_t total = 0;
    for (int i = 0; i < iterations; i++) {
        total += adc_read();
        sleep_us(30); // Shorter sampling separation
    }
    return ((float)total / (float)iterations) * ADC_CONV;
}

void capture_raw_rgb(float *r_out, float *g_out, float *b_out) {
    turn_off_sensor_rgb();
    sleep_ms(30); // Accelerated settling window

    gpio_put(SENS_RED_PIN, 1);   sleep_ms(65); // High-speed shutter pulse
    *r_out = sample_raw_voltage_averages(20);
    gpio_put(SENS_RED_PIN, 0);   sleep_ms(decay_cooldown_r); 

    gpio_put(SENS_GREEN_PIN, 1); sleep_ms(65);
    *g_out = sample_raw_voltage_averages(20);
    gpio_put(SENS_GREEN_PIN, 0); sleep_ms(decay_cooldown_g); 

    gpio_put(SENS_BLUE_PIN, 1);  sleep_ms(65);
    *b_out = sample_raw_voltage_averages(20);
    gpio_put(SENS_BLUE_PIN, 0);  sleep_ms(decay_cooldown_b); 
}

// Non-blocking white status blink function used during scanning loops
void update_idle_blink_status() {
    if (absolute_time_diff_us(get_absolute_time(), next_idle_blink_time) < 0) {
        idle_blink_state = !idle_blink_state;
        next_idle_blink_time = make_timeout_time_ms(120); // Fast 120ms cycle cadence
    }
    
    if (idle_blink_state) {
        set_display_rgb(15, 15, 15); // Subtle white heartbeat pulse
    } else {
        set_display_rgb(0, 0, 0);
    }
}

void run_ldr_latency_calibration() {
    printf("\n======================================================\n");
    printf("    LDR DECAY HORIZON AUTO-TUNING UTILITY             \n");
    printf("======================================================\n");
    printf("Place your brightest object (ideally WHITE) over the sensor.\n");
    printf("Press [ANY KEY] to measure channel transitions...\n");
    clear_serial_buffer(); getchar();

    turn_off_sensor_rgb();
    sleep_ms(500); 
    float v_ambient = sample_raw_voltage_averages(35);

    uint32_t calibrated_latencies[3] = {0, 0, 0};
    uint target_pins[3] = {SENS_RED_PIN, SENS_GREEN_PIN, SENS_BLUE_PIN};
    const char* color_names[3] = {"Red", "Green", "Blue"};

    for (int c = 0; c < 3; c++) {
        uint target_pin = target_pins[c];
        printf(" -> Evaluating %s channel decay envelope... ", color_names[c]);
        
        gpio_put(target_pin, 1);
        sleep_ms(250); 
        float v_lit = sample_raw_voltage_averages(35);
        float peak_delta = (v_lit > v_ambient) ? (v_lit - v_ambient) : 0.05f;

        float target_decay_threshold = v_ambient + (peak_delta * 0.20f);

        gpio_put(target_pin, 0);
        uint32_t decay_start = to_ms_since_boot(get_absolute_time());
        uint32_t elapsed_ms = 0;
        
        while (elapsed_ms < 2000) { 
            float current_v = sample_raw_voltage_averages(5);
            if (current_v <= target_decay_threshold) break;
            sleep_ms(1);
            elapsed_ms = to_ms_since_boot(get_absolute_time()) - decay_start;
        }
        
        calibrated_latencies[c] = (elapsed_ms > 20) ? elapsed_ms : 20;
        printf("Cleared in %lu ms\n", calibrated_latencies[c]);
        sleep_ms(200); 
    }

    decay_cooldown_r = calibrated_latencies[0];
    decay_cooldown_g = calibrated_latencies[1];
    decay_cooldown_b = calibrated_latencies[2];
    latency_calibrated = true; 

    printf("\n>>> DELAY PARAMS SECURED AND INJECTED INTO SAMPLING LOOP <<<\n");
    printf("  * Cooldowns -> Red: %lu ms | Green: %lu ms | Blue: %lu ms\n", decay_cooldown_r, decay_cooldown_g, decay_cooldown_b);
}

void train_new_color_slot() {
    clear_serial_buffer();

    printf("\n======================================================\n");
    printf("    MENU: SELECT PRE-MADE COLOR SLOT TO CALIBRATE     \n");
    printf("======================================================\n");
    for (int i = 0; i < TARGET_COUNT; i++) {
        printf("[%d] %-10s (Display Driver mapping: R:%3d G:%3d B:%3d)\n", 
               i, color_table[i].label, color_table[i].r_disp, color_table[i].g_disp, color_table[i].b_disp);
    }
    printf("Select choice index token (0-%d): ", TARGET_COUNT - 1);
    
    int chosen_idx = -1;
    while (true) {
        int ch = getchar();
        if (ch >= '0' && ch < '0' + TARGET_COUNT) {
            putchar(ch);
            chosen_idx = ch - '0';
            break;
        }
    }
    printf("\nTarget Slot Selected: [%s]\n\n", color_table[chosen_idx].label);

    printf("Enter target lock servo angle output value (0 to 180):\n>> ");
    clear_serial_buffer();
    uint32_t parsed_angle = 90;
    char num_buff[10]; int num_idx = 0;
    while (num_idx < 9) {
        int ch = getchar();
        if (ch == '\r' || ch == '\n') { if (num_idx > 0) break; continue; }
        if (ch >= '0' && ch <= '9') { putchar(ch); num_buff[num_idx++] = (char)ch; }
    }
    num_buff[num_idx] = '\0';
    sscanf(num_buff, "%lu", &parsed_angle);
    if (parsed_angle > 180) parsed_angle = 180;

    printf("\nPlace your [%s] surface directly over the sensor assembly now.\n", color_table[chosen_idx].label);
    printf("Press [ANY KEY] to flash sensor light profiles and store values...\n");
    clear_serial_buffer(); getchar();

    float r = 0, g = 0, b = 0;
    printf("Scanning color signature data... ");
    capture_raw_rgb(&r, &g, &b);
    
    strcpy(trained_profiles[chosen_idx].name, color_table[chosen_idx].label);
    trained_profiles[chosen_idx].r_val = r;
    trained_profiles[chosen_idx].g_val = g;
    trained_profiles[chosen_idx].b_val = b;
    trained_profiles[chosen_idx].servo_angle = (uint16_t)parsed_angle;
    trained_profiles[chosen_idx].disp_r = color_table[chosen_idx].r_disp;
    trained_profiles[chosen_idx].disp_g = color_table[chosen_idx].g_disp;
    trained_profiles[chosen_idx].disp_b = color_table[chosen_idx].b_disp;
    
    if (!trained_profiles[chosen_idx].active) {
        trained_profiles[chosen_idx].active = true;
        active_profile_count++;
    }

    printf("DONE!\nSignature stored: R:%.3fV | G:%.3fV | B:%.3fV -> Locked Angle: %d deg\n", r, g, b, parsed_angle);
}

void print_trained_database() {
    printf("\n--- CURRENT TRAINED DATABASE PROFILES ---\n");
    int active_printed = 0;
    for (int i = 0; i < TARGET_COUNT; i++) {
        if (trained_profiles[i].active) {
            printf(" Slot Index [%d] Name: %-10s | R:%.3fV G:%.3fV B:%.3fV | Lock Servo: %3d deg\n",
                   i, trained_profiles[i].name, trained_profiles[i].r_val, 
                   trained_profiles[i].g_val, trained_profiles[i].b_val, trained_profiles[i].servo_angle);
            active_printed++;
        }
    }
    if (active_printed == 0) printf("Empty matrix database. Please train custom colors using [t].\n");
}

void process_conveyor_sorting_pipeline() {
    if (active_profile_count == 0) {
        printf(">> [WARN] No active trained profiles. Press [t] to calibrate parameters first! <<\n");
        sleep_ms(1000);
        return;
    }

    // 1. Asynchronous check for physical gate release timeout
    if (is_servo_locked) {
        if (absolute_time_diff_us(get_absolute_time(), servo_unlock_time) < 0) {
            is_servo_locked = false; 
            printf("[TIMER EXPIRED] Sorting track cleared. Resuming active belt scanning...\n");
        }
    }

    // 2. High-speed scan pass
    float cur_r = 0, cur_g = 0, cur_b = 0;
    capture_raw_rgb(&cur_r, &cur_g, &cur_b);

    int closest_slot_match = -1;
    float minimum_calculated_distance = 999.0f;

    for (int i = 0; i < TARGET_COUNT; i++) {
        if (!trained_profiles[i].active) continue;

        float delta_r = cur_r - trained_profiles[i].r_val;
        float delta_g = cur_g - trained_profiles[i].g_val;
        float delta_b = cur_b - trained_profiles[i].b_val;
        float calculated_distance = sqrtf((delta_r * delta_r) + (delta_g * delta_g) + (delta_b * delta_b));

        if (calculated_distance < minimum_calculated_distance) {
            minimum_calculated_distance = calculated_distance;
            closest_slot_match = i;
        }
    }

    // 3. Noise gate logic to reject belt surface scratches and dust
    float dist_from_none = 999.0f;
    if (trained_profiles[6].active) { // Index 6 is our "NONE" baseline profile
        float d_r = cur_r - trained_profiles[6].r_val;
        float d_g = cur_g - trained_profiles[6].g_val;
        float d_b = cur_b - trained_profiles[6].b_val;
        dist_from_none = sqrtf((d_r * d_r) + (d_g * d_g) + (d_b * d_b));
    }

    // 4. State Assignment Parsing
    if (closest_slot_match != -1 && minimum_calculated_distance <= MATCH_THRESHOLD) {
        
        // Scenario A: Sensor registers a match to empty belt, OR reflection variation is too weak to be a real item
        if (closest_slot_match == 6 || dist_from_none < BELT_DIRT_THRESHOLD) { 
            if (!is_servo_locked) {
                current_active_angle = trained_profiles[6].active ? trained_profiles[6].servo_angle : 90;
                write_servo_angle(current_active_angle);
                update_idle_blink_status(); // Run the white heartbeat blink when idle
            }
            printf("CONVEYOR: [R:%.3fV G:%.3fV B:%.3fV] -> [EMPTY/DIRTY BELT FILTERED] (Servo: %d deg)\n", 
                   cur_r, cur_g, cur_b, current_active_angle);
        } 
        // Scenario B: Valid item cleanly verified outside background noise parameters
        else { 
            servo_unlock_time = make_timeout_time_ms(2800);
            is_servo_locked = true;
            current_active_angle = trained_profiles[closest_slot_match].servo_angle;
            
            write_servo_angle(current_active_angle);
            set_display_rgb(trained_profiles[closest_slot_match].disp_r, trained_profiles[closest_slot_match].disp_g, trained_profiles[closest_slot_match].disp_b);
            
            printf("CONVEYOR: [R:%.3fV G:%.3fV B:%.3fV] -> DETECTED VALID ITEM: [%s] -> LOCKING SERVO to %d deg (2.8s)\n",
                   cur_r, cur_g, cur_b, trained_profiles[closest_slot_match].name, current_active_angle);
        }
    } else {
        printf("CONVEYOR: [R:%.3fV G:%.3fV B:%.3fV] -> >> UNKNOWN OBJECT SIGNAL OUTSIDE PARAMETERS <<\n", cur_r, cur_g, cur_b);
        if (!is_servo_locked) update_idle_blink_status();
    }
}

void print_user_interface() {
    printf("\n======================================================\n");
    printf("    ANTI-DIRT RELIABLE HIGH-SPEED CONVEYOR SCANNER    \n");
    printf("======================================================\n");
    if (!latency_calibrated) printf(" [!] STATUS: DECAY CALIBRATION REQUIRED BEFORE USE\n");
    else                     printf(" [*] STATUS: FILTER ACTIVE / PILOT READY\n");
    printf("------------------------------------------------------\n");
    printf("[c] Run LDR Physical Latency Auto-Tuning Profile Pass\n");
    printf("[t] Select & Train a Pre-Made Color Matrix Slot (Train NONE on clean belt)\n");
    printf("[p] Print Current Trained Database Configuration\n");
    printf("[m] Trigger Single Manual Match Check Pass\n");
    printf("[a] Start Continuous Active Conveyor Sorting Stream (Blinks White while idle)\n");
    printf("------------------------------------------------------\n");
    printf("Select option token: ");
}

int main() {
    stdio_init_all();
    
    gpio_set_function(DISP_RED_PIN,   GPIO_FUNC_PWM);
    gpio_set_function(DISP_GREEN_PIN, GPIO_FUNC_PWM);
    gpio_set_function(DISP_BLUE_PIN,  GPIO_FUNC_PWM);
    gpio_set_function(SERVO_PIN,      GPIO_FUNC_PWM);
    
    gpio_init(SENS_RED_PIN);   gpio_set_dir(SENS_RED_PIN, GPIO_OUT);
    gpio_init(SENS_GREEN_PIN); gpio_set_dir(SENS_GREEN_PIN, GPIO_OUT);
    gpio_init(SENS_BLUE_PIN);  gpio_set_dir(SENS_BLUE_PIN, GPIO_OUT);
    
    pwm_config led_config = pwm_get_default_config();
    pwm_config_set_clkdiv(&led_config, 4.0f); 
    pwm_init(pwm_gpio_to_slice_num(DISP_RED_PIN),    &led_config, true);
    pwm_init(pwm_gpio_to_slice_num(DISP_GREEN_PIN),  &led_config, true);
    pwm_init(pwm_gpio_to_slice_num(DISP_BLUE_PIN),   &led_config, true);

    pwm_config servo_config = pwm_get_default_config();
    pwm_config_set_clkdiv(&servo_config, 64.0f); 
    pwm_config_set_wrap(&servo_config, SERVO_WRAP);
    pwm_init(pwm_gpio_to_slice_num(SERVO_PIN), &servo_config, true);

    set_display_rgb(0, 0, 0);
    turn_off_sensor_rgb();
    write_servo_angle(90); 

    for (int i = 0; i < TARGET_COUNT; i++) trained_profiles[i].active = false;
    next_idle_blink_time = get_absolute_time();

    adc_init();
    adc_gpio_init(LDR_ADC_PIN);    
    adc_select_input(LDR_ADC_CH);  

    sleep_ms(2000);
    print_user_interface();

    while (true) {
        int incoming_token = getchar_timeout_us(0);
        if (incoming_token == PICO_ERROR_TIMEOUT) { sleep_ms(10); continue; }

        switch (incoming_token) {
            case 'c': case 'C': run_ldr_latency_calibration(); print_user_interface(); break;
            case 't': case 'T': 
                if (!latency_calibrated) printf("\n[REJECTED] Run decay auto-tuning calibration [c] first!\n");
                else                     train_new_color_slot();
                print_user_interface(); break;
            case 'p': case 'P': print_trained_database(); print_user_interface(); break;
            case 'm': case 'M': 
                if (!latency_calibrated) {
                    printf("\n[REJECTED] Run decay auto-tuning calibration [c] first!\n");
                } else {
                    printf("\nExecuting manual pattern scan...\n"); 
                    process_conveyor_sorting_pipeline();
                }
                print_user_interface(); break;
            case 'a': case 'A':
                if (!latency_calibrated) {
                    printf("\n[REJECTED] Action blocked. Run decay auto-tuning [c] first.\n");
                    print_user_interface(); break;
                }
                printf("\nLaunching continuous conveyor sorting stream. Press 'e' or 'q' to stop...\n\n");
                while (true) {
                    process_conveyor_sorting_pipeline();
                    int break_tok = getchar_timeout_us(0);
                    if (break_tok == 'e' || break_tok == 'E' || break_tok == 'q' || break_tok == 'Q') break;
                    sleep_ms(2); // Tight processing delay ensures instantaneous response tracking
                }
                set_display_rgb(0, 0, 0); print_user_interface(); break;
            default: if (incoming_token != '\n' && incoming_token != '\r') print_user_interface(); break;
        }
    }
}

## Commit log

2026-06-21 Solid Parts added
    [Barra superior.SLDPRT, Chapa.SLDPRT, Esteira.SLDPRT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]
2026-06-21 Adicionado parte do diagrama de blocos
2026-06-27 Atualizado Git
    [PlacaSensor-B_Cu.gbl, PlacaSensor-B_Mask.gbs, PlacaSensor-B_Paste.gbp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]
